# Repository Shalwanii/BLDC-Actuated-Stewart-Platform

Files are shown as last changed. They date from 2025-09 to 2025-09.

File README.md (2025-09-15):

# BLDC-Actuated Stewart Platform for Aerial Additive Manufacturing

This repository contains all **CAD models**, **control code**, and **analysis scripts** developed for the Master's thesis:  
*"Feasibility Study of a Brushless DC Actuated Stewart Platform for Aerial Additive Manufacturing"*.

The project investigates the use of **BLDC motors** in a 6-DOF Stewart platform, aiming to achieve **high responsiveness, precision, and lightweight design** suitable for UAV integration.

/CAD  
   /Ball_Joint  
      Ball_Joint_Baseless.f3d  
      Ball_Joint_Baseless.step  
      Ball_Joint_Baseless.stl  

   /Lever_Arm  
      Lever_Arm.f3d  
      Lever_Arm.step  
      Lever_Arm.stl  

   /Motor_Facemount  
      Motor_Facemount.f3d  
      Motor_Facemount.step  
      Motor_Facemount.stl  

   /Moving_Base  
      Moving_Base.f3d  
      Moving_Base.step  
      Moving_Base.stl  

   /Potentiometer_Coupler  
      Potentiometer_Coupler.f3d  
      Potentiometer_Coupler.step  
      Potentiometer_Coupler.stl  

   /Potentiometer_Mount  
      Potentiometer_Case.f3d  
      Potentiometer_Case.step  
      Potentiometer_Case.stl  
      Potentiometer_L_Bracket.f3d  
      Potentiometer_L_Bracket.step  
      Potentiometer_L_Bracket.stl  

   /Shaft  
      Shaft.f3d  
      Shaft.step  
      Shaft.stl  

   /Stationary_Base  
      Stationary_Base.f3d  
      Stationary_Base.step  
      Stationary_Base.stl  

   Final_Platform_Assembly.step  
   Potentiometer.SLDPRT  
   Repeat_Compact.STEP  

/Arduino  
   Single_Motor_Test.ino  
   Sequential_Motor_Test.ino  
   Coordinated_Multi_Motor_Test.ino  

/Matlab  
   stewartIK.m  
   workspace.m  

/Python  
   stewartFK.py  

/Docs  
   README.md
 
```
```
## 🛠️ CAD Models

- **Format Provided:** `.f3d` (Fusion 360 native), `.step` (universal exchange), `.stl` (3D-printable).  
- **Components:**
  - Ball Joint  
  - Lever Arm
  - Motor Facemount
  - Moving Base
  - Potentiometer Coupler
  - Potentiometer Mount
  - Shaft  
  - Stationary Base
  - Moving Platform  
  - Full Assembly  

```
```
## 💻 Code

- **Arduino**  
  -   Single-Motor Calibration: Each motor was driven individually under different tolerance thresholds to tune the PD controller and characterise convergence behaviour with potentiometer feedback.  
  - Sequential Motor Testing: Motors were activated one at a time with random target angles while the others were held neutral, measuring settling time, steady-state error, and reachability within defined angle windows.
  - Coordinated Multi-Motor Evaluation: All six motors were commanded simultaneously and achieved poses were compared against desired ones to assess system-level accuracy, convergence, and pose errors.

- **MATLAB**  
  - Scripts for workspace analysis.  
  - Inverse kinematics implementation for rotary Stewart platform.  

- **Python**  
  - Forward Kinematics to obtain Pose from Joint Angles  

```

```
## ⚡ System Overview

- **Actuators:** Repeat Compact Brushless Planetary 22mm Gearmotor  
- **ESCs:** Repeat Dual AM32 Brushless Drive ESC  
- **Microcontroller (prototype):** Arduino Elegoo Uno R3  
- **Microcontroller (future):** Teensy 4.1  
- **Sensors:** 10kΩ potentiometers (prototype), AS5048A magnetic encoders (planned upgrade)  
- **Fabrication:** FDM 3D printing (PLA)  

```
```
## 📊 Key Features

- Feasibility study of BLDC actuation for Stewart platforms.  
- Evaluation of workspace, precision, and responsiveness.  
- Comparison of sequential vs coordinated motor operation.  
- Pose-level error analysis (translation & orientation).  

```

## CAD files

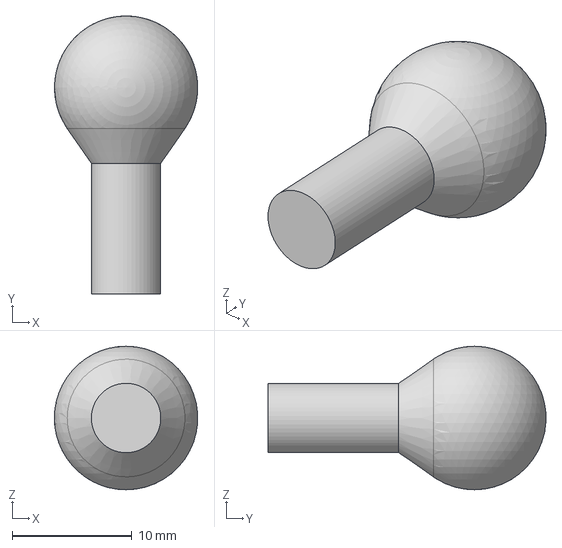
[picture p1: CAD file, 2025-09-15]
CAD/Ball Joint/Ball Joint's Baseless Ball.step
12.0 x 23.2 x 12.0 mm

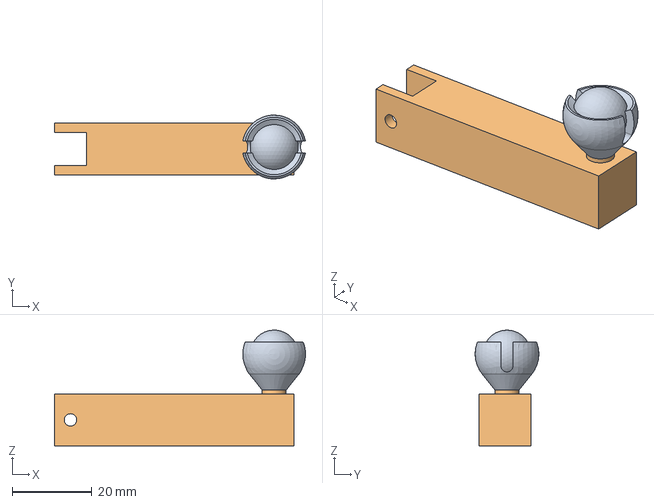
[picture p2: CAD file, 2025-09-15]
CAD/Lever Arm/Lever Arm.step
62.8 x 16.0 x 29.0 mm

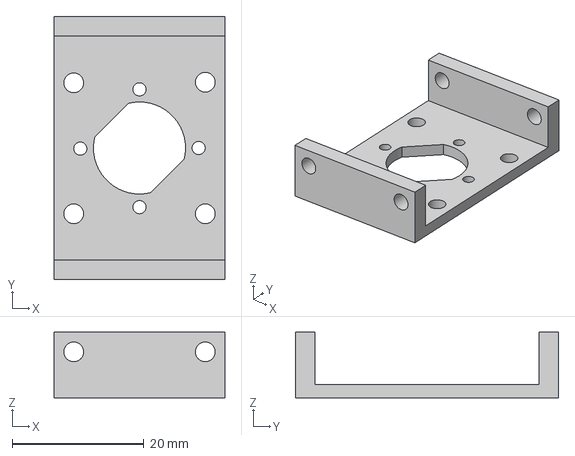
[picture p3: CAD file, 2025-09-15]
CAD/Motor Facemount/Motor Facemount.step
26.0 x 40.0 x 10.0 mm

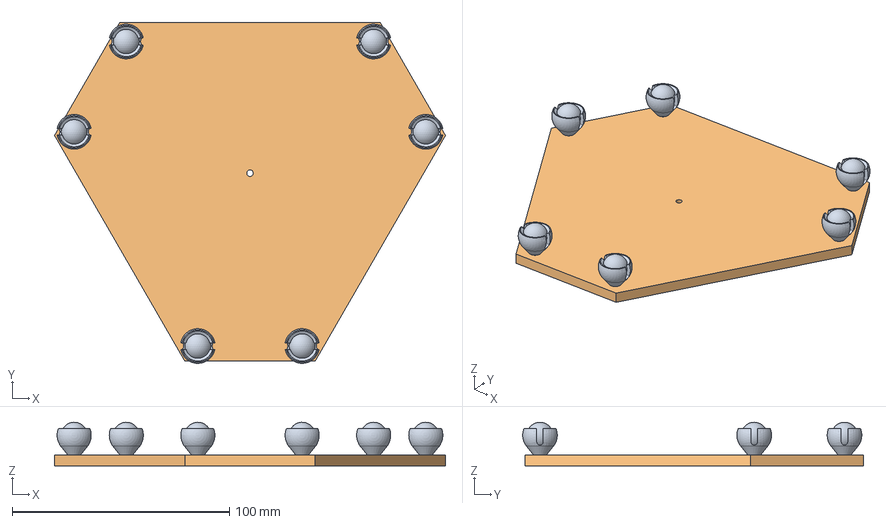
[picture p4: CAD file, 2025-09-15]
CAD/Moving Base/Moving Base.step
180.0 x 156.9 x 20.0 mm

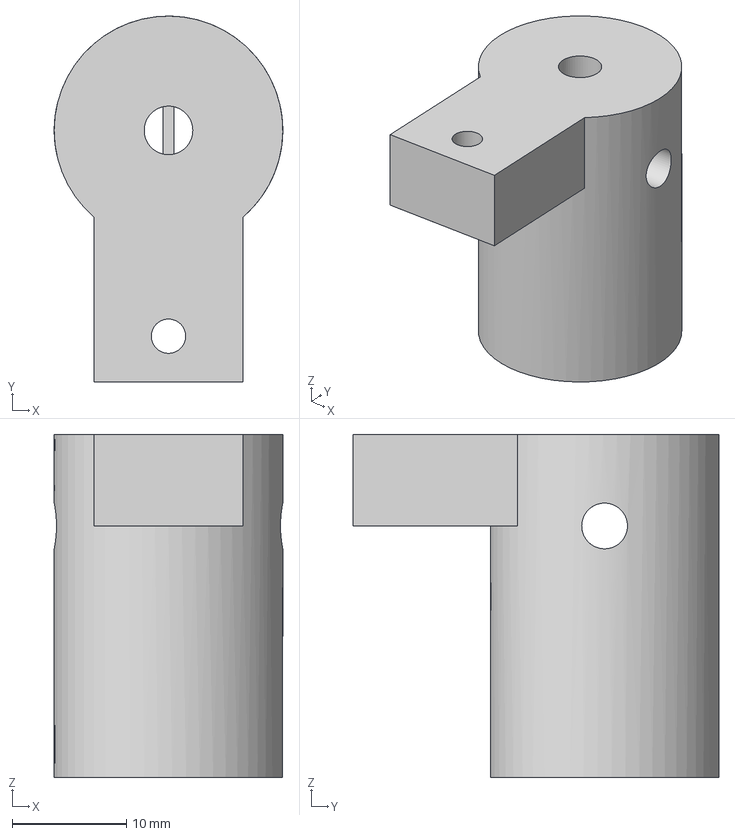
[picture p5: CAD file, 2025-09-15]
CAD/Potentiometer Coupler/Lever Arm Potentiometer Coupler v9.step
20.0 x 32.0 x 30.0 mm

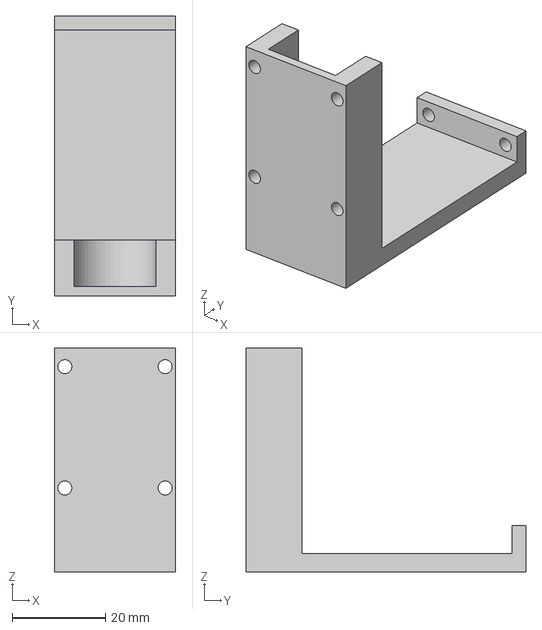
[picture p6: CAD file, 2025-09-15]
CAD/Potentiometer Mount/Potentiometer L-bracket.step
26.0 x 60.0 x 48.0 mm

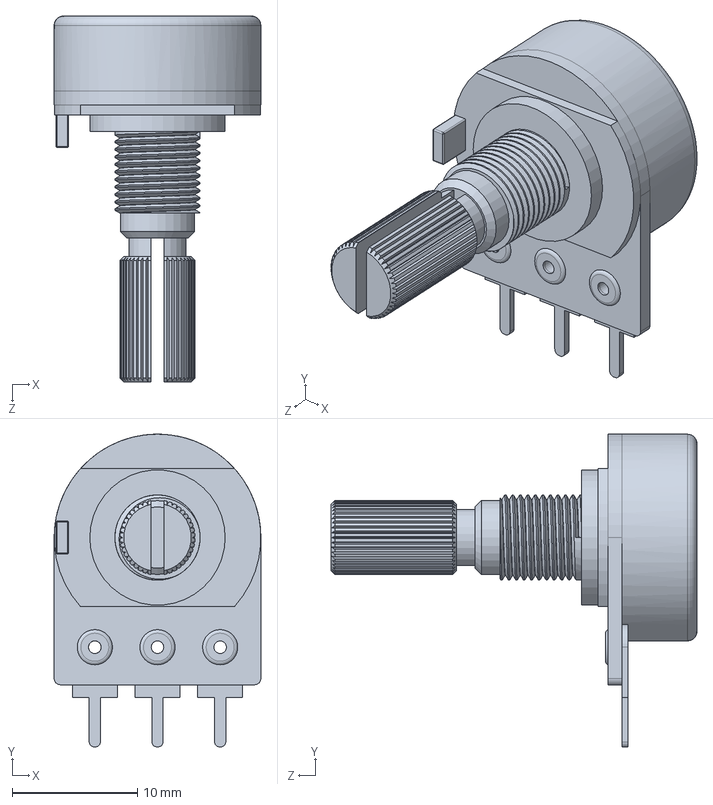
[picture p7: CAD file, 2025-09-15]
CAD/Potentiometer.SLDPRT
16.5 x 24.9 x 29.2 mm

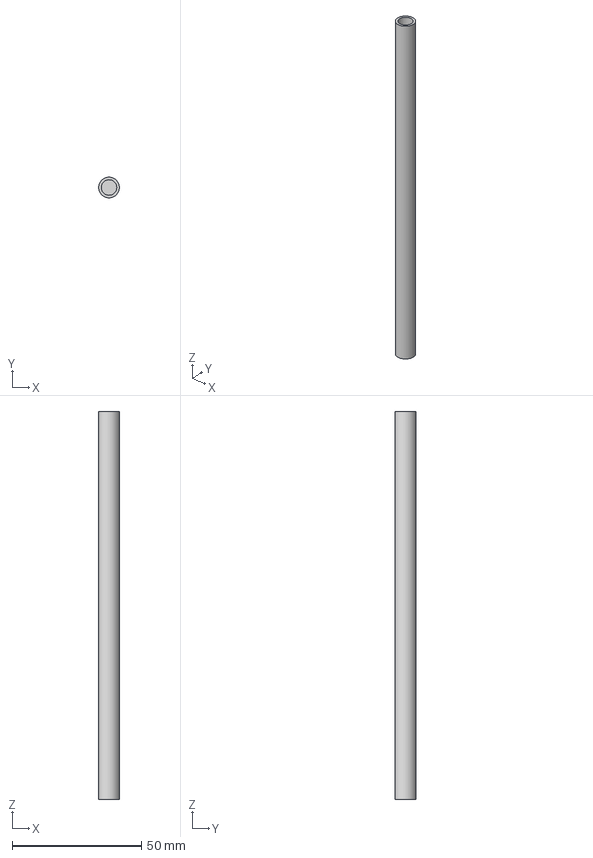
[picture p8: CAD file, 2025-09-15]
CAD/Shaft/Shaft.step
7.99 x 8.00 x 150.0 mm

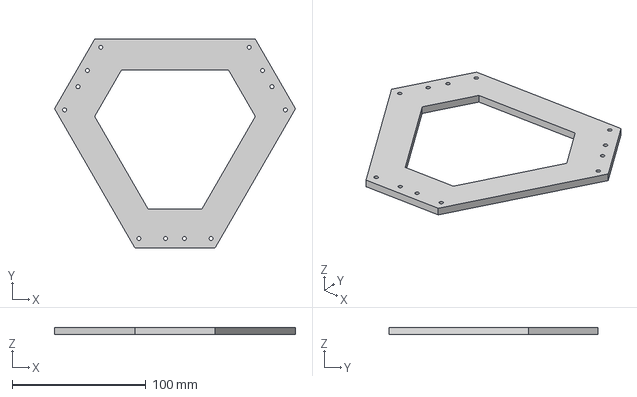
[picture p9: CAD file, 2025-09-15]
CAD/Stationary Base/Stewart's Stationary Base.step
180.0 x 155.9 x 5.00 mm

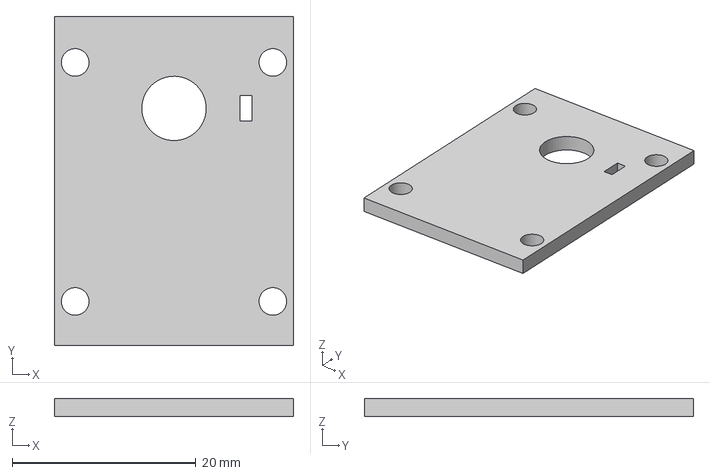
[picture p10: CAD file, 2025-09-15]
CAD/Potentiometer Mount/Potentiometer Case.step
26.0 x 35.8 x 2.00 mm

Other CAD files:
CAD/Ball Joint/Ball Joint's Baseless Ball.f3d
CAD/Ball Joint/Ball Joint's Baseless Ball.stl
CAD/Lever Arm/Lever Arm.f3z
CAD/Lever Arm/Lever Arm.stl
CAD/Motor Facemount/Motor Facemount.f3d
CAD/Motor Facemount/Motor Facemount.stl
CAD/Moving Base/Moving Base.f3z
CAD/Moving Base/Moving Base.stl
CAD/Potentiometer Coupler/Lever Arm Potentiometer Coupler v9.f3d
CAD/Potentiometer Coupler/Lever Arm Potentiometer Coupler v9.stl
CAD/Potentiometer Mount/Potentiometer Case.f3d
CAD/Potentiometer Mount/Potentiometer Case.stl
CAD/Potentiometer Mount/Potentiometer L-Bracket.stl
CAD/Potentiometer Mount/Potentiometer L-bracket.f3d
CAD/Shaft/Shaft.f3d
CAD/Shaft/Shaft.stl
CAD/Stationary Base/Stewart's Stationary Base.f3d
CAD/Stationary Base/Stewart's Stationary Base.stl

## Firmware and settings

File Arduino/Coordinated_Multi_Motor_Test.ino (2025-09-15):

#include <Servo.h>

/* ===== Pins  ===== */
const uint8_t ESC_PINS[6] = {3, 5, 6, 9, 10, 11};   // 1L,1R,2L,2R,3L,3R
const uint8_t POT_PINS[6] = {A0, A1, A2, A3, A4, A5};
const char*   NAMES[6]    = {"1L","1R","2L","2R","3L","3R"};

/* ===== ESC centered PWM ===== */
const int ESC_MID    = 1500;
const int MIN_OFFSET = 25;
const int MAX_OFFSET = 50;

/* ===== Angle↔Count calibration ===== */
const float ZERO_COUNT          = 520.0f;
const float DEG_PER_COUNT_LEFT  = -60.0f / (800.0f - 520.0f);
const float DEG_PER_COUNT_RIGHT = -60.0f / (240.0f - 520.0f);
const float CNT_PER_DEG_LEFT    = 1.0f / DEG_PER_COUNT_LEFT;   // -4.6667
const float CNT_PER_DEG_RIGHT   = 1.0f / DEG_PER_COUNT_RIGHT;  // +4.6667

enum Side { LEFT_SIDE, RIGHT_SIDE };
const Side SIDE[6] = {LEFT_SIDE, RIGHT_SIDE, LEFT_SIDE, RIGHT_SIDE, LEFT_SIDE, RIGHT_SIDE};

inline int   angleToCounts(Side s, float deg) { return (int)lroundf(ZERO_COUNT + deg * ((s==LEFT_SIDE)?CNT_PER_DEG_LEFT:CNT_PER_DEG_RIGHT)); }
inline float countsToAngle(Side s, int counts){ return (counts - ZERO_COUNT) * ((s==LEFT_SIDE)?DEG_PER_COUNT_LEFT:DEG_PER_COUNT_RIGHT); }

/* ===== PD control  ===== */
float Kp_us_per_count     = 0.0025f;
float Kd_us_per_cnt_per_s = 0.50f;
const float DERIV_LP_ALPHA = 0.12f;

/* ===== Arrival / timing  ===== */
const int   ARRIVE_TOL              = 20;        // ±counts to declare arrived
const unsigned long HOLD_MS         = 1000;      // neutral hold (logging)
const unsigned long MOVE_TIMEOUT_MS = 5000;     // full time allowed to reach a pose

/* ===== Safety (angle bounds only) ===== */
const float SAFE_MIN_DEG = -70.0f;
const float SAFE_MAX_DEG =  90.0f;

/* ===== POSES from Stewart IK (deg) =====
   Each row = {1L,1R,2L,2R,3L,3R}
   Replace with your IK outputs:
*/// Order per row: {1L, 1R, 2L, 2R, 3L, 3R} in degrees
const float POSES[][6] = {
  { -1.286f,   1.286f,  -7.929f, -20.571f, -25.286f, -11.571f },  // row 1
  { -5.571f, -21.000f, -13.071f,  -1.929f,  25.929f,  -0.857f },  // row 2
  {-10.500f, -20.786f, -14.571f, -12.857f,  -1.714f, -16.071f },  // row 3
  { 11.786f, -24.000f, -19.714f, -20.357f,   0.429f,   6.643f },  // row 4
  { -9.643f, -26.143f, -19.929f, -18.857f,  -8.143f,  -5.786f },  // row 5
  {-14.143f, -25.286f, -24.429f,  15.000f,  12.429f,   4.929f },  // row 6
  {  2.786f, -19.071f, -28.500f,  -6.000f,  -0.214f,   5.571f },  // row 7
  {-10.714f, -21.429f, -22.929f, -10.286f,  -5.571f,  -5.786f },  // row 8
  {-12.429f, -21.429f, -21.214f,  -1.286f,  -2.143f,  -5.357f },  // row 9
  { -2.571f, -25.500f, -33.214f,  -5.357f,   0.000f,   8.786f },  // row 10
  {-15.214f, -24.643f, -25.714f,   8.143f,   3.214f,  -0.429f },  // row 11
  {-31.500f,   7.071f,  30.000f,  17.143f,   2.786f, -31.071f },  // row 12
  {-34.286f,   1.286f,   4.714f,   4.929f,  -0.643f, -28.714f },  // row 13
  {  7.714f,   2.357f,  -2.143f, -10.500f,  -3.429f,  -8.786f },  // row 14
  { -3.214f, -13.714f, -15.857f, -20.786f, -14.571f,  -4.929f },  // row 15
  {  3.643f,  28.929f,   7.929f, -22.071f, -32.357f,  -2.786f },  // row 16
  {  3.857f,  18.214f, -13.286f, -28.286f, -33.857f,   3.214f },  // row 17
  {-12.643f,   1.714f, -16.714f, -21.214f, -29.143f,  -4.714f },  // row 18
  {-29.357f,   1.286f,  -3.643f,  27.000f,   8.786f,  -3.643f },  // row 19
  {-23.571f,  -9.857f, -18.214f,   9.000f,  -3.429f,  -8.786f },  // row 20
  {-24.214f,  30.000f,  14.571f,   5.571f, -19.714f, -15.000f },  // row 21
  {-28.929f,  32.357f,  25.714f,  25.286f,  -7.500f, -15.214f },  // row 22
  {-20.786f,  27.643f,  18.643f,  25.929f,   2.143f,   5.143f },  // row 23
  {  6.643f,   2.357f, -17.357f,   7.286f,  -0.214f,  25.714f },  // row 24
  {-12.857f,  -9.643f, -19.500f,   4.929f,   0.000f,   8.571f },  // row 25
  {-14.357f, -15.214f, -20.571f,  16.714f,  20.143f,  13.286f },  // row 26
  {-11.357f,  10.929f,  -9.857f,  12.429f,   3.857f,   8.786f },  // row 27
  { 30.214f, -12.000f, -13.286f, -19.714f,  -4.929f,  16.071f },  // row 28
  { -0.214f, -27.000f, -23.571f, -11.786f,   0.000f,  -0.857f },  // row 29
  {  1.929f, -24.429f, -22.071f, -20.357f,  -3.429f,   7.071f },  // row 30
  {  7.714f, -15.000f, -25.500f, -15.857f,  -3.643f,  16.286f },  // row 31
  { -0.857f,  -4.286f,   6.857f, -16.714f, -11.786f,  -3.214f },  // row 32
  { -6.000f, -10.500f,   0.429f, -13.929f, -10.286f,  -4.071f },  // row 33
  {-10.071f, -24.000f,  -7.286f,   1.071f,  18.857f,  -6.214f },  // row 34
  { -1.500f, -31.714f, -24.000f,  -3.857f,  17.357f,  13.286f },  // row 35
  {  0.643f, -32.357f, -31.714f,  -2.786f,  10.071f,  14.786f },  // row 36
  {  0.214f, -30.000f, -27.643f,  -7.714f,   4.286f,   1.286f },  // row 37
  {-21.429f,  -1.714f,  19.714f,   3.643f,   1.071f, -27.214f },  // row 38
  {-31.500f,  -6.000f,  12.643f,  17.143f,   9.429f, -28.071f },  // row 39
  {-28.929f,  -7.929f,   4.286f,   4.286f,   9.214f, -27.214f },  // row 40
  { 22.286f, -20.786f, -10.500f,  -9.000f,  14.571f,  12.643f },  // row 41
  {-12.000f, -26.571f, -15.214f,  -9.214f,   8.357f, -11.786f },  // row 42
  { -4.714f, -30.643f, -14.571f,  -2.143f,  25.929f,  -4.714f },  // row 43
  {-17.143f,  29.786f,  28.714f,   0.000f, -11.571f, -18.000f },  // row 44
  {-16.714f,  10.500f,   7.714f,  -6.643f, -15.429f,  -8.143f },  // row 45
  {-10.714f,  -3.000f, -15.643f, -20.786f, -28.071f,   1.071f },  // row 46
  {-13.929f,   6.429f,   7.071f, -17.786f, -29.357f,  -9.429f },  // row 47
  {-15.214f,  -0.214f,  -7.286f, -22.929f, -31.714f,  -7.714f },  // row 48
  { -9.429f,  -3.643f, -11.786f, -24.643f, -28.071f,  -4.714f },  // row 49
  {-12.857f,   9.429f,  26.143f, -12.214f, -20.357f, -16.071f },  // row 50
};


const int N_POSES = sizeof(POSES)/sizeof(POSES[0]);

/* ===== State ===== */
Servo esc[6];
int   plusEffect[6] = {-1,-1,-1,-1,-1,-1};    // +us -> +counts? (calibrated at startup)
float lastCounts[6] = {NAN,NAN,NAN,NAN,NAN,NAN};
float vel_filt[6]   = {0,0,0,0,0,0};

unsigned long lastMicros = 0;

int   poseIdx = 0;
int   tgtCounts[6];

bool  arrived[6];
unsigned long poseStart = 0;
bool  holding = false;
unsigned long holdStart = 0;
unsigned long snapshotMillis = 0;  // <-- new
unsigned long reach_ms = 0;        // <-- new
bool  finished = false;

/* Snapshot at hold entry */
float snapDeg[6];
const char* snapStatus[6];   // "reached" / "not_reached"

/* ===== Helpers ===== */
int readPotFiltered(uint8_t pin) { long s=0; for (int i=0;i<8;++i) s += analogRead(pin); return (int)(s>>3); }

void calibrateDirection(Servo& e, uint8_t potPin, int &plusEff) {
  int r0 = readPotFiltered(potPin);
  e.writeMicroseconds(ESC_MID + 30); delay(60);
  e.writeMicroseconds(ESC_MID);      delay(40);
  int r1 = readPotFiltered(potPin);
  plusEff = (r1 > r0) ? +1 : -1;     // +μs increased counts?
}

int pdToPulse(float u_us) {
  int sign = (u_us > 0) ? +1 : (u_us < 0 ? -1 : 0);
  int mag  = (int)fabs(u_us);
  if (mag < MIN_OFFSET) mag = MIN_OFFSET;
  if (mag > MAX_OFFSET) mag = MAX_OFFSET;
  return ESC_MID + sign * mag;
}

void neutralAll() { for (int i=0;i<6;++i) esc[i].writeMicroseconds(ESC_MID); }

void beginPose(int p) {
  for (int i=0;i<6;++i) {
    tgtCounts[i] = angleToCounts(SIDE[i], POSES[p][i]);
    arrived[i]   = false;
    lastCounts[i]= NAN;  // reset D-term state
    vel_filt[i]  = 0.0f;
  }
  holding = false;
  poseStart = millis();
}

/* ===== Arduino ===== */
void setup() {
  Serial.begin(115200);

  for (int i=0;i<6;++i) {
    pinMode(POT_PINS[i], INPUT);
    esc[i].attach(ESC_PINS[i]);
    esc[i].writeMicroseconds(ESC_MID);
  }
  delay(3000); // arming

  // Calibrate all channels once
  for (int i=0;i<6;++i) calibrateDirection(esc[i], POT_PINS[i], plusEffect[i]);

  lastMicros = micros();

  // CSV header: added reach_ms
  Serial.println(F("pose,"
                   "status_1L,status_1R,status_2L,status_2R,status_3L,status_3R,pose_status,reach_ms,"
                   "last_1L_deg,last_1R_deg,last_2L_deg,last_2R_deg,last_3L_deg,last_3R_deg"));

  beginPose(0);
}

void loop() {
  if (finished) return;

  // Timing
  unsigned long nowMicros = micros();
  float dt_s = (nowMicros - lastMicros) / 1e6f;
  if (dt_s <= 0) dt_s = 1e-3f;
  lastMicros = nowMicros;

  // Read all channels
  int raw[6]; float ang[6];
  for (int i=0;i<6;++i) { raw[i] = readPotFiltered(POT_PINS[i]); ang[i] = countsToAngle(SIDE[i], raw[i]); }

  // Drive all six (NO CREEP)
  bool allArrived = true;
  bool timedOut   = (millis() - poseStart) > MOVE_TIMEOUT_MS;

  if (!holding) {
    for (int i=0;i<6;++i) {
      // Angle safety only
      if (ang[i] < SAFE_MIN_DEG || ang[i] > SAFE_MAX_DEG) {
        arrived[i] = true;  // stop trying this motor
        esc[i].writeMicroseconds(ESC_MID);
        continue;
      }

      int err = tgtCounts[i] - raw[i];
      int aerr = abs(err);

      // D-term in counts/s, filtered
      if (isnan(lastCounts[i])) lastCounts[i] = raw[i];
      float vel_cnt_s = (raw[i] - lastCounts[i]) / dt_s;
      lastCounts[i] = raw[i];
      vel_filt[i] = (1.0f - DERIV_LP_ALPHA)*vel_filt[i] + DERIV_LP_ALPHA*vel_cnt_s;

      if (aerr <= ARRIVE_TOL) {
        arrived[i] = true;
        esc[i].writeMicroseconds(ESC_MID);
      } else if (!timedOut) {
        arrived[i] = false;
        float u_base = Kp_us_per_count * (float)err - Kd_us_per_cnt_per_s * vel_filt[i];
        int desiredSignCounts = (err > 0) ? +1 : -1;
        int sideSign          = (plusEffect[i] == desiredSignCounts) ? +1 : -1;
        float u_signed        = sideSign * fabs(u_base);
        int pwm               = pdToPulse(u_signed);
        esc[i].writeMicroseconds(pwm);
      } else {
        // timed out: stop driving this channel
        arrived[i] = false; // will be not_reached
        esc[i].writeMicroseconds(ESC_MID);
      }

      if (!arrived[i]) allArrived = false;
    }

    // Enter HOLD when either all in tolerance OR timeout elapsed
    if (allArrived || timedOut) {
      // Snapshot once at hold entry; decide per-motor status here
      for (int i=0;i<6;++i) {
        snapDeg[i] = ang[i];
        int finalErrCounts = abs(tgtCounts[i] - raw[i]);
        bool thisReached   = (finalErrCounts <= ARRIVE_TOL) && !timedOut;
        snapStatus[i] = thisReached ? "reached" : "not_reached";
        esc[i].writeMicroseconds(ESC_MID); // neutral during hold
      }
      snapshotMillis = millis();                 // <-- stamp
      reach_ms = snapshotMillis - poseStart;     // <-- how long pose took
      holdStart = snapshotMillis;
      holding = true;
    }
  } else {
    // In HOLD: remain neutral (NO CREEP)
    for (int i=0;i<6;++i) esc[i].writeMicroseconds(ESC_MID);

    // End of hold → log & advance
    if (millis() - holdStart >= HOLD_MS) {
      bool poseOK = true;
      for (int i=0;i<6;++i) if (snapStatus[i][0] == 'n') poseOK = false;

      Serial.print(poseIdx + 1); Serial.print(",");
      Serial.print(snapStatus[0]); Serial.print(",");
      Serial.print(snapStatus[1]); Serial.print(",");
      Serial.print(snapStatus[2]); Serial.print(",");
      Serial.print(snapStatus[3]); Serial.print(",");
      Serial.print(snapStatus[4]); Serial.print(",");
      Serial.print(snapStatus[5]); Serial.print(",");
      Serial.print(poseOK ? "reached" : "not_reached"); Serial.print(",");
      Serial.print(reach_ms); Serial.print(",");  // <-- new column
      Serial.print(snapDeg[0], 3); Serial.print(",");
      Serial.print(snapDeg[1], 3); Serial.print(",");
      Serial.print(snapDeg[2], 3); Serial.print(",");
      Serial.print(snapDeg[3], 3); Serial.print(",");
      Serial.print(snapDeg[4], 3); Serial.print(",");
      Serial.println(snapDeg[5], 3);

      // Next pose
      poseIdx++;
      if (poseIdx >= N_POSES) {
        neutralAll();
        finished = true;
        return;
      } else {
        holding = false;
        beginPose(poseIdx);
      }
    }
  }
}

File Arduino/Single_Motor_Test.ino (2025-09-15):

#include <Servo.h>

/* ===== Pins ===== */
const uint8_t ESC_PINS[6] = {6, 9, 11, 10, 3, 5};   // 1L,1R,2L,2R,3L,3R
const uint8_t POT_PINS[6] = {A4, A5, A1, A0, A2, A3};
const char*   NAMES[6]    = {"1L","1R","2L","2R","3L","3R"};

/* ===== ESC centered PWM ===== */
const int ESC_MID    = 1500;
const int MIN_OFFSET = 20;
const int MAX_OFFSET = 35;

/* ===== Angle↔Count calibration ===== */
const float ZERO_COUNT          = 520.0f;
const float DEG_PER_COUNT_LEFT  = -60.0f / (800.0f - 520.0f);  // -0.2142857
const float DEG_PER_COUNT_RIGHT = -60.0f / (240.0f - 520.0f);  // +0.2142857
const float CNT_PER_DEG_LEFT    = 1.0f / DEG_PER_COUNT_LEFT;   // -4.6666667
const float CNT_PER_DEG_RIGHT   = 1.0f / DEG_PER_COUNT_RIGHT;  // +4.6666667

enum Side { LEFT_SIDE, RIGHT_SIDE };
const Side SIDE[6] = {LEFT_SIDE, RIGHT_SIDE, LEFT_SIDE, RIGHT_SIDE, LEFT_SIDE, RIGHT_SIDE};

inline int angleToCounts(Side s, float deg) {
  return (int)lroundf(ZERO_COUNT + deg * ((s == LEFT_SIDE) ? CNT_PER_DEG_LEFT : CNT_PER_DEG_RIGHT));
}
inline float countsToAngle(Side s, int counts) {
  float dpc = (s == LEFT_SIDE) ? DEG_PER_COUNT_LEFT : DEG_PER_COUNT_RIGHT;
  return (counts - ZERO_COUNT) * dpc;
}

/* ===== Targets (angles) ===== */
const float degTargets[] = {-30.0f, 0.0f, +30.0f};
const int   N_TGT = sizeof(degTargets)/sizeof(degTargets[0]);

/* ===== Sync hold ===== */
const int ARRIVE_TOL = 20;             // counts
const unsigned long HOLD_MS = 2000;    // ms (sync hold)

/* ===== PD gains ===== */
float Kp_us_per_count     = 0.0025f;
float Kd_us_per_cnt_per_s = 0.75f;
const float DERIV_LP_ALPHA = 0.12f;

/* ===== Repeat cycles ===== */
const int N_CYCLES = 5;
int cyclesDone = 0;

/* ===== Safety limits ===== */
const float SAFE_MIN_DEG = -65.0f;   // SAFETY
const float SAFE_MAX_DEG =  70.0f;   // SAFETY
const unsigned long POT_TIMEOUT_MS = 200; // if pot stuck, force neutral

/* ===== State ===== */
Servo esc[6];
int   plusEffect[6];
float lastCounts[6];
float vel_filt[6];
unsigned long lastPotUpdate[6];   // SAFETY

int   idx = 0;
bool  arrived[6] = {false};
unsigned long holdStart = 0;
bool  holding = false;

unsigned long lastMicros = 0;
bool finished = false;

/* ---- Helpers ---- */
int readPotFiltered(uint8_t pin) {
  long s=0; for (int i=0;i<8;++i) s += analogRead(pin);
  return (int)(s>>3);
}a

void calibrateDirection(Servo& esc, uint8_t potPin, int &plusEff) {
  int r0 = readPotFiltered(potPin);
  esc.writeMicroseconds(ESC_MID + 30);
  delay(60);
  esc.writeMicroseconds(ESC_MID);
  delay(40);
  int r1 = readPotFiltered(potPin);
  plusEff = (r1 > r0) ? +1 : -1;
}

int pdToPulse(float u_us) {
  int sign = (u_us > 0) ? +1 : (u_us < 0 ? -1 : 0);
  int mag  = (int)fabs(u_us);
  if (mag < MIN_OFFSET) mag = MIN_OFFSET;
  if (mag > MAX_OFFSET) mag = MAX_OFFSET;
  return ESC_MID + sign * mag;
}

/* ===== Arduino ===== */
void setup() {
  Serial.begin(115200);

  for (int i=0;i<6;++i) {
    pinMode(POT_PINS[i], INPUT);
    esc[i].attach(ESC_PINS[i]);
    esc[i].writeMicroseconds(ESC_MID);
    lastPotUpdate[i] = millis();  // SAFETY
  }
  Serial.println(F("Arming 6 ESC channels at 1500us..."));
  delay(3000);

  for (int i=0;i<6;++i) calibrateDirection(esc[i], POT_PINS[i], plusEffect[i]);

  for (int i=0;i<6;++i) { lastCounts[i] = NAN; vel_filt[i] = 0.0f; }

  lastMicros = micros();

  Serial.println(F("All motors ACTIVE, sync sequence -30,0,+30 deg"));
  Serial.println(F("time_ms,"
                   "raw_1L,ang_1L,tgt_1L,pwm_1L,"
                   "raw_1R,ang_1R,tgt_1R,pwm_1R,"
                   "raw_2L,ang_2L,tgt_2L,pwm_2L,"
                   "raw_2R,ang_2R,tgt_2R,pwm_2R,"
                   "raw_3L,ang_3L,tgt_3L,pwm_3L,"
                   "raw_3R,ang_3R,tgt_3R,pwm_3R"));
}

void loop() {
  if (finished) return;

  unsigned long nowMicros = micros();
  float dt_s = (nowMicros - lastMicros) / 1e6f;
  if (dt_s <= 0) dt_s = 1e-3f;
  lastMicros = nowMicros;

  int raw[6]; float ang[6]; int pwm[6];
  float tgtDeg = degTargets[idx];

  bool allArrived = true;

  for (int i=0;i<6;++i) {
    raw[i] = readPotFiltered(POT_PINS[i]);
    ang[i] = countsToAngle(SIDE[i], raw[i]);

    // SAFETY: check pot change
    static int lastRaw[6] = {0};
    if (raw[i] != lastRaw[i]) {
      lastRaw[i] = raw[i];
      lastPotUpdate[i] = millis();
    }

    bool potStuck = (millis() - lastPotUpdate[i]) > POT_TIMEOUT_MS;

    // SAFETY: angle or pot failure
    if (ang[i] < SAFE_MIN_DEG || ang[i] > SAFE_MAX_DEG || potStuck) {
      esc[i].writeMicroseconds(ESC_MID);
      pwm[i] = ESC_MID;
      arrived[i] = true;   // force "arrived" to avoid deadlock
      continue;
    }

    int tgt = angleToCounts(SIDE[i], tgtDeg);
    int err = tgt - raw[i];
    int aerr = abs(err);

    if (isnan(lastCounts[i])) lastCounts[i] = raw[i];
    float vel = (raw[i] - lastCounts[i]) / dt_s;
    lastCounts[i] = raw[i];
    vel_filt[i] = (1.0f - DERIV_LP_ALPHA)*vel_filt[i] + DERIV_LP_ALPHA*vel;

    pwm[i] = ESC_MID;

    if (aerr <= ARRIVE_TOL) {
      arrived[i] = true;
      esc[i].writeMicroseconds(ESC_MID);
    } else {
      arrived[i] = false;
      float u_base = Kp_us_per_count * (float)err - Kd_us_per_cnt_per_s * vel_filt[i];
      int desiredSignCounts = (err > 0) ? +1 : -1;
      int sideSign = (plusEffect[i] == desiredSignCounts) ? +1 : -1;
      float u_signed = sideSign * fabs(u_base);
      pwm[i] = pdToPulse(u_signed);
      esc[i].writeMicroseconds(pwm[i]);
    }

    if (!arrived[i]) allArrived = false;
  }

  // Sync hold logic
  if (allArrived) {
    if (!holding) { holding = true; holdStart = millis(); }
    else if (millis() - holdStart >= HOLD_MS) {
      idx++;
      holding = false;
      if (idx >= N_TGT) {
        idx = 0;
        cyclesDone++;
        if (cyclesDone >= N_CYCLES) {
          for (int i=0;i<6;++i) esc[i].writeMicroseconds(ESC_MID);
          Serial.println(F("# Finished all cycles, motors neutral, logging stopped."));
          finished = true;
        }
      }
    }
  } else {
    holding = false;
  }

  if (!finished) {
    Serial.print(millis()); Serial.print(",");
    for (int i=0;i<6;++i) {
      Serial.print(raw[i]); Serial.print(",");
      Serial.print(ang[i],2); Serial.print(",");
      Serial.print(tgtDeg,1); Serial.print(",");
      Serial.print(pwm[i]);
      if (i<5) Serial.print(",");
    }
    Serial.println();
  }

}
